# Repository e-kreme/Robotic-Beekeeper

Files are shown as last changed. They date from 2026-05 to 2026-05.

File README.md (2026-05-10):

# Robotic Beekeeper
Bachelor's thesis at Brno University of Technology, Faculty of Information Technology (VUT FIT), 2025/2026.

**Author:** Eliška Křeménková (xkremee00)\
**Supervisor:** doc. RNDr. Pavel Smrž, Ph.D.

## Overview

An automated beehive monitoring system consisting of two hardware nodes and a server:

- **Sensor node (ESP32-S3)** - measures hive weight, outdoor temperature, and indoor temperature, humidity, and pressure, publishes readings to an MQTT broker every 5 minutes
- **Camera node (Raspberry Pi 5)** - detects and counts bees at the hive entrance using a YOLO11n model with ByteTrack tracking, distinguishes bees carrying pollen and direction of movement
- **Server (Raspberry Pi 4)** - receives all data via MQTT, stores it in a SQLite database, runs anomaly detection using LightGBM predictions, and visualises everything in Grafana with email alerts

## Repository Structure

```
.
├── data/
│   ├── BeeObserver/          # BeeObserver (BoB) dataset used for model training
│   │   └── {year}/49.csv
│   ├── sensor_data.csv       # Real sensor readings from the deployment period
│   └── bee_count_log.csv     # Real bee traffic counts from the deployment period
│
├── docs/
│   ├── installation_guide.md # Step-by-step setup for all nodes and the server
│   ├── user_manual.md        # How to use and monitor the system
│   └── schematic.png         # Sensor node wiring schematic
│
├── src/
│   ├── firmware/
│   │   ├── beehive.ino       # ESP32-S3 Arduino sketch
│   │   └── config.h.example  # WiFi and MQTT credentials template
│   │
│   ├── scripts/
│   │   ├── bee_counter.py                  # Camera node - real-time bee counting
│   │   ├── subscriber.py                   # Server - MQTT subscriber and database writer
│   │   ├── forecast_anomaly_detection.py   # Server - hourly prediction and anomaly detection
│   │   ├── photo_script.py                 # Utility - time-lapse photo capture (dataset collection)
│   │   └── config.py.example               # MQTT configuration template
│   │
│   ├── models/
│   │   ├── machine_learning.ipynb                      # Model training notebook (LightGBM + LSTM)
│   │   ├── lgb_separate_weight-delta-noOutlier.txt     # Trained LightGBM weight model
│   │   ├── lgb_separate_t-i-3.txt                      # Trained LightGBM temperature model
│   │   ├── lgb_feature_cols.json                       # Feature column list for inference
│   │   └── mybeesyolo11.ncnn.zip                       # YOLO11n bee detection model (NCNN format)
│   │
│   ├── config/
│   │   ├── beehive.conf                    # Mosquitto broker configuration
│   │   ├── beehive-subscriber.service      # systemd service for the subscriber script
│   │   ├── contrab.example                 # Cron entry for forecast_anomaly_detection.py
│   │   ├── grafana.ini.smtp.example        # Grafana SMTP email alert configuration template
│   │   └── Beekeeper5_grafana_export.json  # Grafana dashboard export
│   │
│   └── 3d_models/                          # SolidWorks parts and assembly for the hive scale and camera module
│
├── tex_src/                  # LaTeX source files for the thesis
├── plakat.pdf                # Project poster
├── requirements.txt          # Python dependencies
├── LICENSE
└── README.md
```

## Data

### Deployment Data

Real sensor and camera data collected during the deployment period (April–May 2026):
- `data/sensor_data.csv` - weight, temperatures, humidity, pressure (5-minute intervals)
- `data/bee_count_log.csv` - individual bee crossing events with direction and class
Both files were exported from the SQLite database on the Raspberry Pi 4.

### Training Data

The LightGBM and LSTM models were trained on the **BeeObserver (BoB)** dataset - sensor data from instrumented honey bee colonies recorded in Germany between 2019 and 2022. Colony 49 is used across all four available years.

Dataset source: [BeeObserver on Zenodo](https://zenodo.org/records/10407693)

## Quick Start

See [`docs/installation_guide.md`](docs/installation_guide.md) for full step-by-step instructions for all three nodes and the server.

### Sensor Node (ESP32-S3)

1. Install Arduino IDE and required libraries (see installation guide)
2. Copy `src/firmware/config.h.example` to `src/firmware/config.h` and fill in credentials
3. Flash `src/firmware/beehive.ino`

### Camera Node (Raspberry Pi 5)

1. Create a virtual environment with system-wide packages and install dependencies
2. Copy `src/scripts/config.py.example` to `src/scripts/config.py` and fill in credentials
3. Unzip the YOLO model to `~/Desktop/beehive/`
4. Run `python3 src/scripts/bee_counter.py`

### Server (Raspberry Pi 4)

1. Install Mosquitto, SQLite, and Grafana (see installation guide)
2. Start the subscriber as a systemd service
3. Add the cron job for anomaly detection
4. Import the Grafana dashboard from `src/config/Beekeeper5_grafana_export.json`

## Model Training

The `src/models/machine_learning.ipynb` notebook contains the full training pipeline:
- Data loading and feature engineering from the BeeObserver dataset
- LightGBM training (separate models for weight delta and internal temperature)
- LSTM training as a comparison model
- Anomaly detection evaluation
Run from the repository root with the `data/BeeObserver/` directory present.

## License

See [`LICENSE`](LICENSE).

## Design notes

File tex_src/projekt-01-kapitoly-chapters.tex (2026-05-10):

\chapter{Úvod}
Včely medonosné patří mezi nejvýznamnější opylovače a jejich úloha v~zemědělství i ochraně krajiny je nezastupitelná. V~posledních desetiletích však včelstva čelí rostoucímu tlaku způsobenému parazity, onemocněními i invazivními predátory. Včasná detekce těchto hrozeb je pro včelaře klíčová, avšak tradiční vizuální kontrola úlu je časově náročná, závislá na~zkušenostech včelaře a zachycuje stav včelstva pouze v okamžiku návštěvy stanoviště.

Moderní technologie umožňují tato omezení částečně překonat prostřednictvím kontinuálního automatizovaného monitorování. Měření fyzikálních veličin, jako jsou hmotnost úlu, vnitřní teplota nebo vlhkost, umožňuje sledovat stav včelstva nepřetržitě po celý rok a odhalit odchylky signalizující problém ještě před fyzickou kontrolou. Kamerová analýza česna pak doplňuje senzorová měření o~přímé informace o~letové aktivitě včelstva.

Tato práce navazuje na bakalářskou práci Bc.~Kataríny Chovancové, která se zabývala návrhem kamerového systému pro monitorování česna úlu s~detekcí včel, matky a vosy. Cílem předkládané práce je původní řešení rozšířit tak, aby poskytovalo komplexnější vhled do stavu a zdraví včelstva.

Osobní motivací pro volbu tématu je propojení dvou oblastí zájmu -- včelařství a moderních technologií. Včelařství je v~mé rodině dlouhodobě zakořeněno, protože můj otec se mu již řadu let věnuje. Právě z pozorování jeho práce pramení snaha včelám lépe porozumět a přispět k usnadnění péče o~ně.

Práce je členěna do několika kapitol. Kapitola~\ref{vcelareni} uvádí čtenáře do problematiky včelařství, představuje základy oboru, popisuje nejvýznamnější choroby, škůdce a patologické stavy včelstev, definuje měřitelné veličiny relevantní pro monitorování a shrnuje vybraná existující komerční řešení. Běžně používaným hardwarovým komponentám v oblasti monitorování včelstev se věnuje kapitola \ref{sec:hardware}. Kapitola \ref{sec:iot_komunikace} představuje principy Internetu věcí a komunikačních technologií, které tvoří základ pro volbu komunikační infrastruktury navrženého systému. Kapitola \ref{sec:strojove_uceni} pojednává o~metodách strojového učení, predikci časových řad a detekci anomálií, jež jsou využity v~analytické vrstvě systému, a dále o~přístupech počítačového vidění, na~nichž je založeno kamerové sledování česna a klasifikace včel. Kapitola~\ref{sec:zhodnoceni_navrh} na~základě teoretického rozboru formuluje požadavky na~systém a představuje jeho návrh. Zbývající kapitoly popisují fyzickou konstrukci, implementaci a testování zařízení v~reálných podmínkách na~včelařském stanovišti, porovnávají dosažené výsledky s~existujícími řešeními a navrhují možné směry budoucího vývoje.

\chapter{Včelařství a moderní technologie} \label{vcelareni}
Tato kapitola se zabývá problematikou včelařství z~pohledu současných technologických možností a jejich využití při monitorování včelstev. Nejprve je stručně představeno včelařství jako obor. Následně je rozebrán význam sledování stavu úlu, které umožňuje včasnou detekci problémů a efektivnější řízení včelstva. Důležitá část kapitoly je věnována identifikaci měřitelných veličin, které lze využít k hodnocení stavu včelstva, například hmotnosti úlu, teploty či vlhkosti. Součástí kapitoly je také přehled nejvýznamnějších chorob, škůdců a patologických stavů, které mohou včelstva postihovat. Závěrem jsou představeny existující komerční systémy, jejich vlastnosti a omezení.

\section{Úvod do včelařství}
Včelařství neboli \textit{apikultura} je jedním z~nejstarších řemesel s~historií datující se až do~starověku \cite{Gerstmeier}. Jedná se o~oblast na pomezí biologie, zemědělství a ochrany krajiny. V~širším smyslu spočívá včelařství v~chovu a péči o~včelstva umístěná v~umělých a uspořádaných úlech. 

V~této práci je pod pojmem \textit{včela} vždy míněna včela medonosná (\textit{Apis mellifera}), druh společenského blanokřídlého hmyzu vytvářejícího trvalé kolonie (včelstva) s~kastovní organizací (matka, dělnice, trubci). Na území České republiky se standardně chová v~rámci včelařské praxe \cite{naturaBohemica}.

\section{Význam monitorování úlu}
Tradiční metodou sledování stavu úlu je vizuální kontrola, v~tomto kontextu jsou tím míněny zejména kontroly na začátku včelařské sezóny. Včelař typicky začíná pozorováním česna, kde se zaměřuje na letovou aktivitu včel, její charakter a intenzitu, množství mrtvých včel či přínos pylu. Zkušenější včelaři dokáží dle barvy pylu rozeznat jednotlivé druhy rostlin, ze~kterých pyl pochází \cite{Storch}. Již na základě těchto vjemů lze určit, v~jakém stavu se včelstvo nachází po zimním období.

Následně včelař prohlíží podložky pod úlem, kde lze nalézt další indicie k~vitalitě včel. Zde lze například sledovat spad kleštíka včelího (\textit{Varroa destructor}) způsobujícího onemocnění zvané \textit{varroáza}, poškozené včely či uhynulý plod \cite{Gerstmeier}. Teprve v~závěrečné fázi prohlídky dochází k~otevření úlu a kontrole jeho vnitřního stavu.

Tradiční inspekce představuje základní nástroj chovu včel, jelikož včelaři umožňuje v~reálném čase vyhodnocovat jejich sílu, zdravotní stav a potřebu dalších zásahů. Při jediné návštěvě tak lze získat komplexní přehled o~množství zásob, přítomnosti matky, případných příznacích onemocnění nebo nedostatku prostoru. Na základě těchto poznatků je pak včelař schopen provést odpovídající zásah, například přikrmování, rozšíření prostoru nebo léčbu. Velmi důležitou součást tvoří průběžná dokumentace zjištěného stavu, která umožňuje sledovat vývoj včelstva v~čase a účinnost jednotlivých, typicky léčebných, zásahů \cite{Gerstmeier}.

Přesto mají tyto kontroly své limity. Bývají vysoce závislé na znalostech a zkušenostech samotného včelaře, ale i fyzicky a časově náročné, zejména pro odlehlá stanoviště. Zároveň poskytují pouze okamžité informace o~stavu, nelze tedy zachycovat plynulé změny probíhající mezi jednotlivými návštěvami. Za příklad lze uvést pozvolné slábnutí včelstva v~důsledku nemocí nebo dlouhodobého nedostatku snůšky \cite{Cecchi}. Časté a neopatrné otevírání úlu může narušit vnitřní mikroklima, zvyšovat stres včel i poškozovat plod vlivem nepříznivých venkovních podmínek. Některé patologické stavy jsou v~raných fázích obtížně rozpoznatelné pouhým okem a vyžadují laboratorní vyšetření nebo specializované diagnostické metody -- tradiční vizuální prohlídka je sama o~sobě nemusí včas zachytit \cite{Ritter}.

V~následující části textu budou představeny nejvýznamnější choroby, škůdci a patologické stavy, které mohou včelstva postihovat. Vybraný přehled se zaměřuje zejména na~onemocnění plodu a dospělých včel, na~parazity a další infekce.

\subsubsection*{Varroa destructor}
\textit{Varroa destructor}, česky kleštík zhoubný či kleštík včelí, je parazitický roztoč, který způsobuje onemocnění zvané varroáza. Původem pochází z~oblasti Indie a jihovýchodní Asie, v~současné době je však rozšířen prakticky po celém světě. Výjimku tvoří Austrálie a Oceánie. V~Československu se poprvé objevil v~roce 1978 \cite{varroaza}.

V~současnosti se jedná o~jedno z~nejzávažnějších onemocnění včelstev. Roztoč parazituje jak na dospělých včelách, tak na plodu. Živí se hemolymfou, tedy tělní tekutinou larev a kukel, u~dospělých včel pak převážně tukovým tělískem, navíc tím může přenášet i další nakažlivé nemoci. Samička roztoče do plodové buňky vniká těsně před jejím zavíčkováním. V~buňce proběhne kompletní vývoj parazita a po vylíhnutí včely spolu s~ní vyběhne 2--6 oplozených samic roztoče, přičemž každá z~nich může tento proces zopakovat až sedmkrát \cite{vuvVarroaza}. Parazit častěji napadá trubčí plod, jelikož trubci jej dokážou přenést i do okolních kolonií, matečníky nenapadá.

Napadení způsobuje poškození stavby těla vylíhnutých včel, jako například deformovaná křídla, zkrácený zadeček. Pokud lze spatřit kleštíka na dospělém jedinci, bývá včelstvo zpravidla již velmi silně napadeno. I~když včelstvo navenek nevykazuje zřejmé příznaky, nemoc jej oslabuje, což může spolu s~dalšími vlivy (virózy, nedostatek potravy) vést k~úhynu celé kolonie \cite{Ritter}.

Kvůli závažnosti tohoto onemocnění musí každý registrovaný včelař povinně výskyt roztoče sledovat a včelstva léčit. Výsledky se poté evidují. Povinná je také kontrola zimní měli na přítomnost parazitů a případné navazující léčebné opatření.

\begin{figure}[H]
	\centering
    \begin{subfigure}[b]{0.5\textwidth}
        \centering
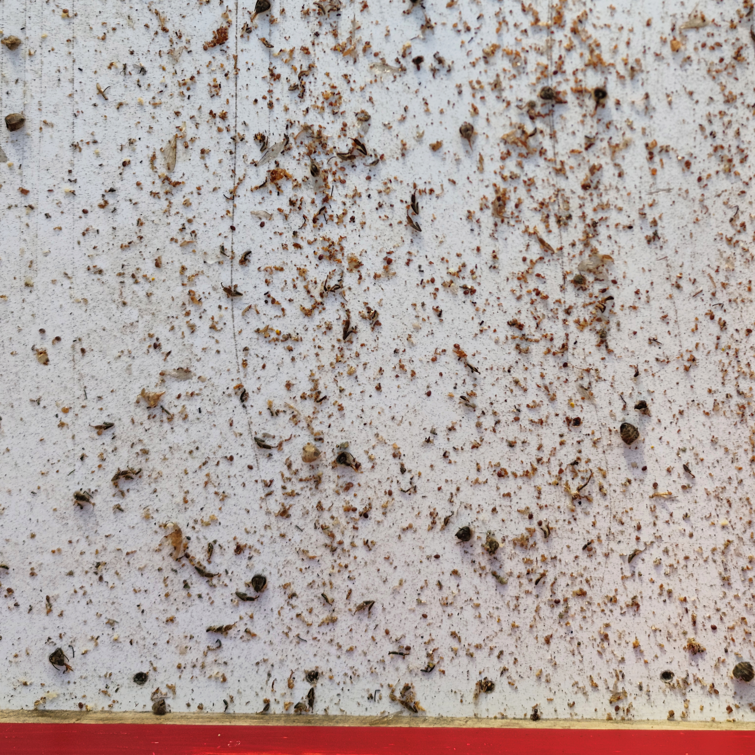
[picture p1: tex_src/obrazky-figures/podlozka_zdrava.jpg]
        
        \caption{Zdravé včelstvo}
        \label{fig:podlozka_zdrava}
    \end{subfigure}\hfill\begin{subfigure}[b]{0.5\textwidth}
        \centering
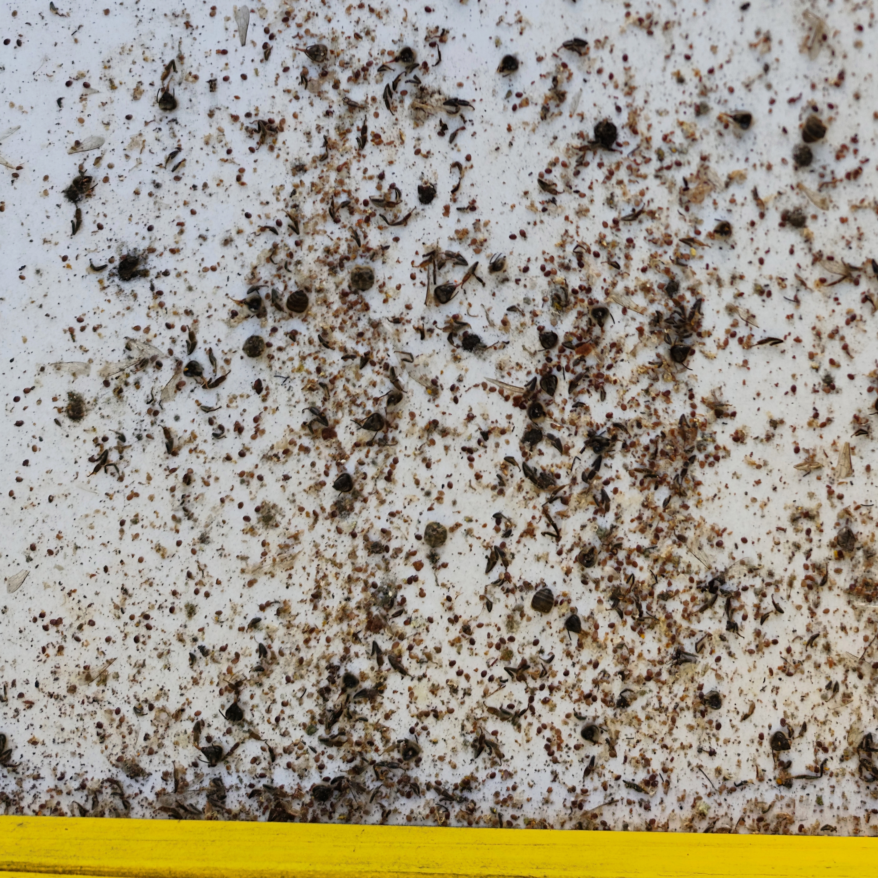
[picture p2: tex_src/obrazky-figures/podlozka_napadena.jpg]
        
        \caption{Napadené včelstvo}
        \label{fig:podlozka_napadena}
    \end{subfigure}
	
	\caption{Srovnání podložky zdravého a napadeného včelstva při podzimním léčení. Vlevo podložka s~minimálním spadem roztoče \textit{Varroa destructor}, vpravo s~výrazným výskytem.}
	\label{fig:srovnani_spadu}
\end{figure}

\subsubsection*{Další onemocnění}
Mezi další nemoci lze zařadit mor včelího plodu. Jedná se o~vysoce nakažlivé bakteriální onemocnění zavíčkovaného plodu, jehož původcem je bakterie \textit{Paenibacillus larvae}. Dospělé jedince nenapadá, ti však mohou nemoc přenášet, například při loupežích v~jiných úlech. Nemoc může mezi jednotlivými koloniemi přenést i včelař, a to křížovou kontaminací při kontrolách.

Spóry této bakterie dokážou přežít v~prostředí úlu (plásty, med, úlové vybavení) až desítky let. K~nákaze dochází po pozření těchto spor larvami, jež následně umírají. Nákazu lze poznat propadlými a děravými víčky, hnilobou, zbytky plodů a zejména pak zápachem. Při silném rozvoji onemocnění postihuje většinu plodu, v~důsledku čehož včelstvo slábne a může až uhynout \cite{Ritter}.

Mor včelího plodu je považován za neléčitelné onemocnění, proto má mnoho zemí velmi striktní hygienická a likvidační opatření. Při nálezu výskytu ho musí včelař dle zákona neprodleně oznámit, z~postižené kolonie je odebrán vzorek a zaslán do laboratoře. Napadenou kolonii pak musí majitel zlikvidovat, typicky utracením včelstva a spálením veškerého kontaminovaného materiálu či dekontaminací ozářením \cite{csvMor}.

Existuje také evropský mor včelího plodu, který naopak napadá otevřený, nezavíčkovaný plod, jenž hyne ještě před zavíčkováním. Toto onemocnění ale nebývá vždy fatální pro celé včelstvo \cite{Ritter}.

\subsubsection*{Škůdci}
Nemoci a parazité nejsou tím jediným, co včelstva zatěžuje. Významnou roli v~této oblasti hrají různí škůdci, kteří samotné včely loví, rabují zásoby a zabíjejí larvy. I samotné včely často rabují okolní kolonie.

Vosy a sršně patří mezi nejvýznamnější přirozené predátory včel, protože napadají jak včely, tak i oslabená či špatně chráněná včelstva. Na včely si počkají před česnem, kde je loví a odnášejí jako potravu pro své vlastní larvy. Případně pronikají až dovnitř úlu, kde rabují med, pyl i plod. V~evropských podmínkách mezi hlavní druhy těchto škůdců patří vosa obecná (\textit{Vespula vulgaris}) a sršeň obecná (\textit{Vespa crabro}). 

Zdravé včelstvo si s~několika jedinci dokáže poradit samo. Proti sršním se například využívá zúžení vstupu do úlu kvůli jejich velikosti. Problém však v~poslední době tvoří jiný druh sršně, proti kterému se stala tato metoda ochrany neúčinná. Tím je sršeň asijská (\textit{Vespa velutina}), jedná se o~invazivní druh, který se rozšiřuje po Evropě. V~České republice se výskyt potvrdil na podzim roku 2023 \cite{svscrSrsenAsijska}. Je o~něco menší než sršeň obecná a redukce česna ji proto nedokáže zastavit. Evropské včely se proti ní samy bránit příliš nedokážou, proto mohou být útoky těchto predátorů pro včelstvo i fatální \cite{monceau2014}. Článek navíc uvádí, že ve Francii, kam byla sršeň do Evropy v~roce 2004 zavlečena, bylo v~roce 2010 oslabeno či zničeno 30\,\% úlů.

Z~řad drobnějších škůdců lze uvést například zavíječe voskového. Larvy tohoto motýla se živí voskem, zejména plásty, ve kterých se nachází včelí plod. Dále pak i mravenci, kteří si vytvářejí hnízda v~polystyrenové vrstvě zateplených úlů \cite{Ritter}.

V~neposlední řadě se jedná o živočichy, jako jsou ptáci nebo drobní hlodavci, kteří úl poškozují spíše mechanicky. V~zimě jej mohou vyhledávat jako úkryt a zdroj potravy.

\subsubsection*{Rojení}
Rojení představuje přirozený způsob rozmnožování včelstev, kdy se jedno silné včelstvo rozdělí na dvě nebo více částí. Typicky stará matka vytváří roj a úl opouští, aby ustoupila matce nové. Pro včelaře je velmi obtížné se na tuto událost připravit. Většinou se jí snaží předcházet s~využitím různých opatření, například rozšířením úlu, tedy přidáním takzvaných \textit{rámků s~mezistěnkou}, aby měly včely další prostor pro ukládání zásob. K~dalším opatřením se řadí přistřižení matčiných křídel \cite{ivcelarstviRojeni}. Nejdůležitější jsou však pravidelné prohlídky rámků, při nichž včelař kontroluje, zda včely nezakládají \textit{matečníky}, tedy buňky, ze kterých vyrostou včelí matky.

Rojení probíhá od jara až do konce června a lze jej rozdělit na \textit{prvoroj}, kdy vylétá stará matka, \textit{druhoroj}, kdy vylétá nová neoplozená matka. Někdy může dojít ještě k~dalším rojením: \textit{třetiroj} atd. Takové chování včel se nazývá \textit{rojová nálada}. K~jejím znakům se řadí velké množství včel, plodu, zásob a snůšky, také zakládání matečníků. Tyto buňky lze nalézt na spodní straně plástu a jsou výrazně větší než ostatní. Čas rojení nastává v~devátý den od zavíčkování matečníku \cite{Gerstmeier}.

I~přesto, že se jedná o~naprosto přirozený proces v~životě včelstva, je pro včelaře negativní, jelikož tím přichází o~velkou část zásob i létavek. Včelstvo pak zůstává oslabené a nová matka neklade vajíčka, protože ještě není oplodněná. Včelař má proto za cíl vyletělý roj chytit a buď z~něj vytvořit novou kolonii, nebo včely vrátit zpět k~té původní.

\section{Měřitelné veličiny} \label{sec:veliciny}
Moderní přístupy k~monitorování včelstev se opírají o~kontinuální měření fyzikálních veličin přímo v~úlu či jeho bezprostřední blízkosti. Přitom žádná veličina není sama o~sobě dostačující pro poskytnutí uceleného obrazu o~stavu dané kolonie -- teprve jejich kombinace a sledování v~čase umožňuje rozpoznat jak normální průběh včelařského roku, tak odchylky značící problém \cite{Cecchi}.

V~rámci systémů využívajících senzory pro monitoring se nejčastěji měří hmotnost, teplota a relativní vlhkost. Některá zařízení přidávají ještě měření atmosférického tlaku, zvuku, oxidu uhličitého či aktivity na česně \cite{Sabic2025}. V~následující části textu jsou popsány základní veličiny -- jejich způsob měření, typické hodnoty v~průběhu roku a znaky rizikových stavů.

\subsubsection*{Hmotnost}
Hmotnost celého úlu je jednou z~veličin s~nejvyšší informační hodnotou, kterou lze při monitorování včelstev sledovat. Měří se pomocí takzvaných \textit{úlových vah}, tedy tenzometrickým snímačem umístěným pod úlem. Získaná data se pak často přenášejí do vzdáleného úložiště. Výhodou tohoto způsobu měření je, že nevyžaduje žádný zásah do úlu a může probíhat nepřetržitě po celý rok.

Hmotnost se v~průběhu roku mění v~závislosti na sezóně. Na jaře a v~létě, v~době snůšky, dochází k~pravidelnému přírůstku -- včely nosí pyl a nektar, matka klade vajíčka a zásoby přibývají. Zároveň dochází i k~denním změnám: v~ranních hodinách hmotnost poklesne, když včely opouštějí úl. Ve večerních hodinách naopak stoupá, jak se včely vracejí s~nektarem \cite{Cecchi}. V~zimním období naopak hmotnost pozvolna klesá, protože včelstvo spotřebovává zásoby. Průměrná zimní spotřeba se pohybuje okolo 6--15 kg, v~závislosti na velikosti kolonie a délce zimního období \cite{domaciVcelarstvi}. 

\begin{figure}[H]
	\centering
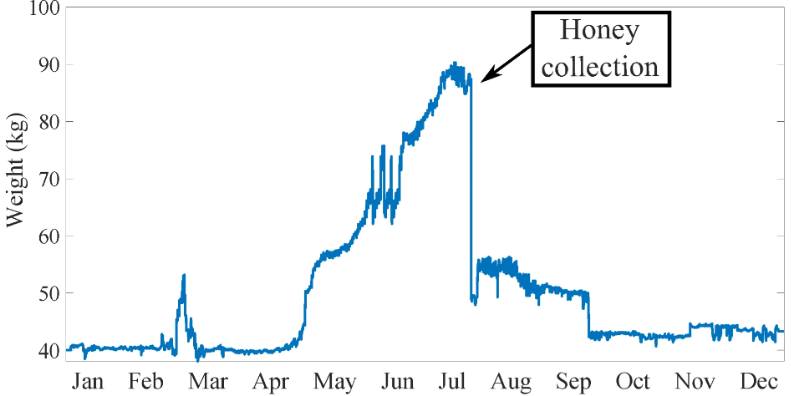
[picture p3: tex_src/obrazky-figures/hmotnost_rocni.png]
    
	\caption[Roční průběh hmotnosti úlu.]{Roční průběh hmotnosti úlu.\footnotemark}
	\label{fig:hmotnost_rocni}
\end{figure}
\footnotetext{Graf pochází z~\cite{Cecchi}, Obrázek 3d.}

Právě v~interpretaci odchylek od těchto očekávaných vzorců spočívá největší přínos průběžného vážení. Náhlý pokles hmotnosti v~řádu 3--4 kg, který lze vidět na obrázku \ref{fig:hmotnost_rojeni}, bývá charakteristickým příznakem rojení. Velká část \textit{létavek} i stará matka úl opouštějí, čímž se jeho hmotnost jednorázově výrazně sníží \cite{Cecchi}. Tento projev je na hmotnostní křivce dobře identifikovatelný a může sloužit jako základ pro včasné upozornění včelaře, který tak může roj odchytit nebo alespoň reagovat na pozměněný stav včelstva.

\begin{figure}[H]
	\centering
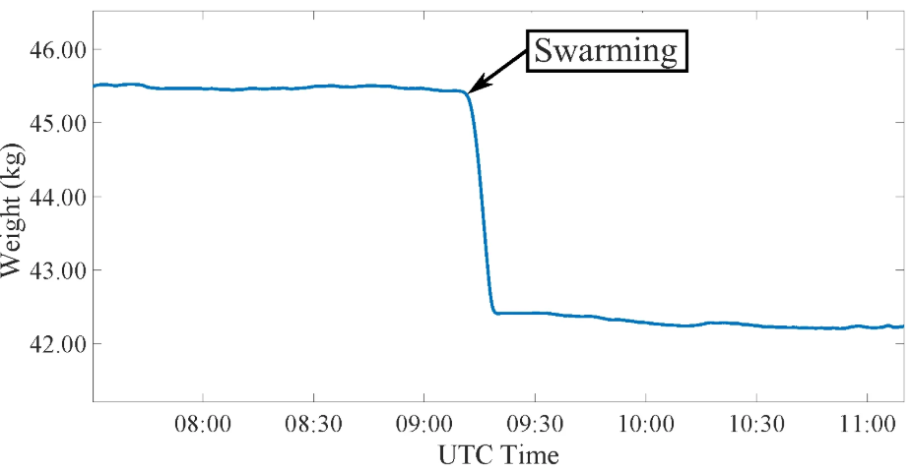
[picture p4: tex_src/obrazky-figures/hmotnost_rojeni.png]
    
	\caption[Změna hmotnosti při události rojení.]{Změna hmotnosti při události rojení.\footnotemark}
	\label{fig:hmotnost_rojeni}
\end{figure}
\footnotetext{Graf pochází z~\cite{Cecchi}, Obrázek 12a.}

Dále pak postupný úbytek hmotnosti mimo zimní období může znamenat hladovění kolonie, kdy včelám nestačí vlastní zásoby a je potřeba přikrmování. Naopak náhlý a extrémní pokles hmotnosti téměř na nulu může indikovat krádež nebo převrácení úlu \cite{dsouza2023hivelinkiotbasedsmart}.

Při sledování těchto změn hmotnosti v~čase je však vždy důležitý sezónní kontext, jelikož stejná změna může mít zcela jiný význam například v~lednu a v~červenci. Z~hlediska datové kvality se ukazuje jako vhodné pracovat s~průměry za delší časové intervaly nebo provádět měření ve stejnou denní dobu, protože surová data mohou obsahovat výrazný šum způsobený pohybem včel, větrem nebo vibracemi \cite{Cecchi}.

\subsubsection*{Teplota}
Teplota je veličinou, která odráží biologickou aktivitu včelstva nejpříměji, míněna je samozřejmě teplota uvnitř úlu. Okolní teplota slouží spíše jako kontext k~hodnotám hmotnosti či letové aktivity (nízká teplota znamená nízkou aktivitu včel). Včely disponují schopností aktivně regulovat teplotu uvnitř úlu v~závislosti na aktuálních potřebách včelstva \cite{Tautz2021}. Měření teploty proto poskytuje přímý vhled do fyziologického stavu kolonie.

Pro měření se nejčastěji využívá digitálních teplotních senzorů, případně kombinovaných, které kromě teploty měří i další veličiny, jako relativní vlhkost či atmosférický tlak. Zásadní roli hraje i umístění senzoru: nejpřesnější informace o~stavu plodového hnízda poskytuje senzor umístěný přímo uprostřed meziplástového prostoru v~centru úlu. Gradient teploty uvnitř úlu je přitom velmi výrazný -- od středu k~okrajům může dosahovat i 10--15\,°C \cite{Stabentheiner2021}, proto systémy s~více senzory poskytují lepší obraz o~stavu kolonie.

V~době, kdy matka klade vajíčka a v~úlu se nachází plod, udržují včely v~plodovém hnízdě teplotu v~úzkém rozmezí 34--36\,°C \cite{Stabentheiner2021} (kniha \textit{Fenomenální včely} \cite{Tautz2021} uvádí interval 33--36\,°C). Tato hodnota podmiňuje správný vývoj larev a kukel. Odchylky od zmíněné teploty mohou mít negativní dopad na kvalitu vylíhnutého plodu. Existence stabilní teploty v~tomto rozmezí je proto spolehlivým nepřímým ukazatelem přítomnosti matky a aktivity plodového hnízda. Naopak pokles teploty v~centru úlu pod 30\,°C v~průběhu hlavní sezóny by měl být signálem k~fyzické kontrole, jelikož může naznačovat ztrátu včelí matky nebo jiný závažný stav kolonie.

V~zimním období včely netvoří aktivní plodové hnízdo a shlukují se do tzv. \textit{zimního chomáče}. Ten funguje jako živý izolátor: teplota v~jeho středu se pohybuje okolo 15--25\,°C \cite{Gerstmeier}, zatímco na povrchu může klesnout k~10\,°C. To je totiž teplota, při níž včely ztrácejí schopnost pohybu \cite{Tautz2021}. Postupný nárůst teploty od přelomu ledna a února signalizuje, že matka opět začíná klást vajíčka a včelstvo se připravuje na jaro.

Teplotní data jsou také jedním z~nejspolehlivějších indikátorů blížícího se úhynu kolonie. Studie Minaud et al. \cite{Minaud} ukázala, že sledování teplotní variability uvnitř úlu v~průběhu zimování umožňuje s~přesností přes 96,8\,\% rozlišit přezimující kolonie od těch, které zimu nepřežijí. Umírající včelstvo postupně ztrácí schopnost udržovat potřebnou teplotu, včely ztrácejí schopnost pohybu a vnitřní teplota se přibližuje teplotě venkovní, viz obrázek \ref{fig:teplota_zima_uhyn}.

\begin{figure}[H]
	\centering
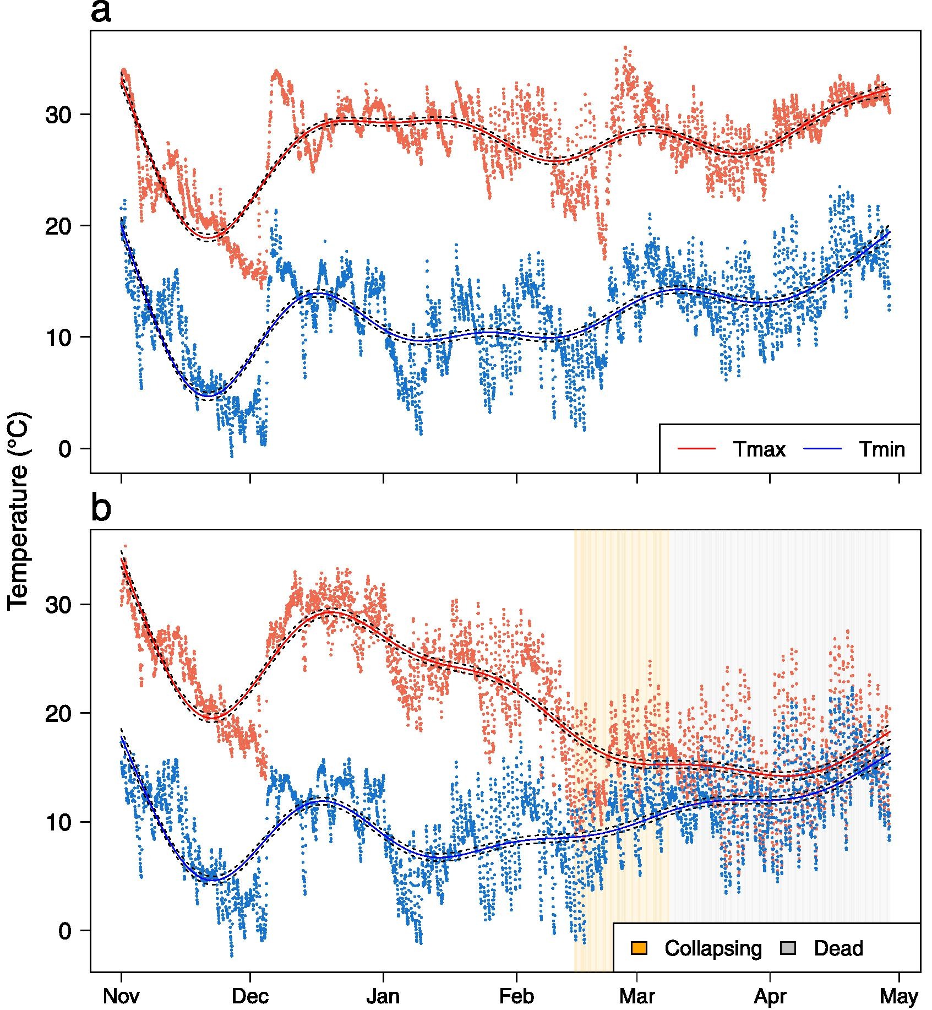
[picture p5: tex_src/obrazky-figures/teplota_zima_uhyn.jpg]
    
	\caption[Porovnání zdravého (a) a uhynulého (b) včelstva v~zimním období.]{Porovnání zdravého (a) a uhynulého (b) včelstva v~zimním období.\footnotemark}
	\label{fig:teplota_zima_uhyn}
\end{figure}
\footnotetext{Grafy pochází z~\cite{Minaud}, Obrázek 2.}

Naopak krátkodobý nárůst teploty v~kombinaci s~nárůstem vlhkosti může předcházet samotnému odletu roje. Roj se zahřívá, a až jeho teplota stoupne na 35\,°C, vyletí ven \cite{Tautz2024}. Včely před rojením větrají úl (víření křídel na česně) a zvyšují svou pohybovou aktivitu, což se projeví i na senzorech \cite{Cecchi}.

V~letních měsících může naopak přílišné horko způsobit, že včely začnou intenzivně větrat česno. Pokud tyto snahy nestačí, včely se na česně začnou ve větším množství shromažďovat. V~extrémních případech je nutný zásah včelaře \cite{Stabentheiner2021}.

\subsubsection*{Relativní vlhkost} \label{veliciny-vlhkost}
Ačkoliv se může na první pohled zdát, že se jedná o~veličinu, která není tolik důležitá, relativní vlhkost úzce souvisí s~několika klíčovými procesy v~životě kolonie. Měří se pomocí kapacitních senzorů. Praktickým problémem při dlouhodobém nasazení jsou samotné včely, které mohou vnitřní senzory obalovat propolisem či voskem. To může způsobovat odchylky měření až úplný výpadek senzoru, což lze následně pozorovat například na grafu naměřených hodnot. Tento jev byl zdokumentován při měření plynů v~úlu \cite{Rigakis2023} a autoři problém vyřešili uložením senzoru do ochranné krabičky.

Nejzásadnější funkcí regulace vlhkosti v~úlu je zpracování nektaru na med. Čerstvě přinesený nektar obsahuje 60--80\,\% vody. Aby byl med kvalitní a nezačal kvasit, musí včely jeho vlhkost snížit pod 20\,\% \cite{nettie}. Tohoto dosahují aktivním větráním. Díky tomuto procesu vlhkost v~úlu výrazně stoupá, zejména v~nočních hodinách, kdy odpařená voda zůstává uvnitř. Sledování nočního nárůstu vlhkosti může sloužit jako nepřímý indikátor intenzity snůšky.

Pro správný vývoj a přežití vajíček je nezbytná relativní vlhkost alespoň 55\,\% v~oblasti plodového hnízda, ideální je však až 90--95\,\% \cite{Linton2019}. Samotné plodové hnízdo udržují včely v~rozmezí přibližně 40--70\,\% RH prostřednictvím aktivního větrání \cite{Linton2019}. Dlouhodobá vlhkost výrazně přesahující tuto hranici, nebo naopak klesající pod 40\,\% může signalizovat poruchu regulačního mechanismu, tedy oslabení nebo zmenšení kolonie.

V~zimním období představuje nadměrná vlhkost jedno z~rizik, která mohou přezimující včelstvo oslabit nebo poškodit. Kondenzace vlhkosti na stěnách úlu a plástech může vést ke tvorbě plísní, poškození zimních zásob nebo přímo k~navlhnutí chomáče, což výrazně zvyšuje energetické nároky na jeho vytápění \cite{Linton2019}. Správné větrání úlu v~zimě proto není jen otázkou eliminace vlhkosti z~dechu včel, ale přímo podmínkou úspěšného přezimování.

Relativní vlhkost může být také jedním z~indikátorů předcházejícího rojení. Bezprostředně před odletem roje bylo v~některých měřeních zaznamenáno krátkodobé zvýšení jak teploty, tak vlhkosti uvnitř úlu \cite{Cecchi} -- pravděpodobně v~důsledku zvýšené aktivity a tělesného tepla shlukujících se rojových včel. Samotná vlhkost však nestačí jako jediný prediktor, proto je vhodné ji kombinovat s~teplotou či dalšími veličinami.

\subsubsection*{Letová aktivita}
Letová aktivita představuje počet včel procházejících česnem za jednotku času a jejich směr pohybu. Jedná se o~veličinu odrážející vnější sběrací část včelstva. Zatímco teplota a hmotnost informují převážně o~dění uvnitř úlu, letová aktivita zachycuje, jak intenzivně kolonie komunikuje s~okolním prostředím \cite{Meikle2015}. Z~biologického pohledu zodpovídají za letovou aktivitu včely \textit{létavky}. Právě letová aktivita proto úzce souvisí s~dostupností snůšky v~okolí a s~celkovou silou a zdravotním stavem kolonie.

Principů pro automatizované měření této veličiny existuje celá řada. Mezi historicky nejpoužívanější patří infračervené senzory nebo fotoelektrické závory. Modernější přístupy zahrnují kapacitní senzory, RFID čipy přilepené na hrudní část jedinců, které umožňují sledování konkrétních včel, kamerové systémy zpracovávající video pomocí algoritmů pro sledování objektů nebo Dopplerův radar. Podrobnější informace uvádí sekce \ref{senzor-let}. Každá z~metod má své výhody i nevýhody týkající se přesnosti, invazivnosti, náročnosti zpracování či citlivosti na změny osvětlení nebo počasí \cite{Williams2023}.

Letová aktivita silně závisí na vnějších podmínkách, zejména na teplotě a intenzitě slunečního záření. Včely typicky nelétají při teplotách pod 10\,°C, při dešti nebo silném větru. Studie Clarke et al. \cite{Clarke2018} ukázala, že teplotou a slunečním zářením lze vysvětlit až 78\,\% variability v~letové aktivitě měřené na česnu. Tato silná závislost na počasí je na jedné straně praktickým omezením, protože naměřené hodnoty musíme interpretovat v~kontextu aktuálních meteorologických podmínek, na druhé straně právě odchylky od předpovídané aktivity mohou být chápány jako rizikový stav \cite{Meikle2015}.

Takové stavy jsou například snížená aktivita při jinak příznivém počasí, což může naznačovat oslabení kolonie, ztrátu létavek v~důsledku otravy pesticidy nebo přítomnosti predátora.

Jarní nárůst letové aktivity bývá také jedním z~nejdříve pozorovatelných signálů jarního rozvoje včelstva, a to ještě předtím, než jsou patrné změny na vahách. První orientační prolety, v~závislosti na geografické poloze, u~nás začínají přibližně od konce února, jakmile teplota překročí 10\,°C \cite{beeinfo}. V~rámci proletů se včely orientují a nosí první potravu. U~kamerových systémů lze dokonce určit dostupnost specifických druhů rostlin v~okolí úlů dle pylových roušek na zadních nožkách včel \cite{Cecchi}.

Největším praktickým omezením automatického sledování letové aktivity zůstává technická náročnost instalace a údržby senzorů. Zařízení mohou včely stresovat a ty je následně znečišťují, jak bylo zmíněno výše. Kamerové systémy jsou citlivé na venkovní světelné podmínky a vyžadují výpočetní kapacitu pro zpracování videa v~reálném čase nebo jeho archivaci. Proto se v~praxi letová aktivita měří spíše pro výzkumné účely, nikoli jako součást komerčních monitorovacích systémů pro běžné včelaře.

\section{Některá existující komerční řešení a jejich srovnání} \label{sec:komercni_reseni}
Současný trh s~technologiemi pro monitorování včelstev lze rozdělit do dvou základních kategorií. První tvoří modulární senzorová řešení, která se přidávají k~existujícímu úlovému vybavení -- typicky se jedná o~úlové váhy doplněné teplotními a vlhkostními senzory s~bezdrátovým přenosem dat. Druhou kategorii představují integrované inteligentní systémy, kde je monitorovací technologie nedílnou součástí samotného úlu, v~některých případech se jedná i o~prvky robotické automatizace. Zatímco první kategorie je zaměřena na standardního včelaře hledajícího dostupné rozšíření stávající praxe, druhá cílí na profesionální a komerční provozovatele. V~následující části textu je představeno několik komerčních řešení dostupných na trhu.

\subsubsection*{BeeSage}
Lotyšský produkt BeeSage HiveScale v2 je primárně hmotnostní systém s~důrazem na jednoduchost nasazení a mezinárodní dostupnost. Váha měří hmotnost úlu a okolní teplotu s~hodinovým intervalem, součástí zařízení je i GPS modul pro sledování polohy úlu, který slouží jako ochrana před krádeží. Zařízení komunikuje prostřednictvím SIM karty zahrnuté v~ceně (399 EUR) a data jsou dostupná přes webovou aplikaci s~možností exportu. Výrobce také pracuje na integraci akustického monitorování v~budoucích verzích produktu \cite{beesage}. 

\subsubsection*{VeluBee}
VeluBee je český produkt s~více než desetiletou historií vývoje. Aktuálně je ve~třetí generaci hardwaru a nabízí tři produktové varianty. VeluBee Hive je kompletní sada obsahující řídicí jednotku, jednu váhu a solární panel, cena začíná na 9900 Kč a zahrnuje roční licenci. VeluBee One je přídavná váha pro rozšíření stávající sestavy (od~7300 Kč). VeluBee LUNIT je specifická offline varianta s~displejem pro lokality bez internetového připojení (od~8200 Kč). Oproti jiným řešením nabízí výrazně širší softwarové funkce: webová a mobilní aplikace zahrnuje interaktivní grafy s~možností porovnání více úlů, automatickou detekci snůšky, detekci krádeže a vyrojení, včelařský deník s~fotogalerií, správu kolonií a exporty dat ve~formátu CSV. Systém podporuje připojení přes Wi-Fi i IoT sítě a nabízí možnost vzdáleného tárování (vynulování) váhy přes internet \cite{velubee}.

\subsubsection*{BeeHive Monitoring}
Slovenský e-shop BeeHiveMonitoring.com nabízí rozsáhlé produktové portfolio zahrnující jak standardní úlové váhy s~řídicí jednotkou pro jejich správu, tak specializované senzorové moduly. Takovým modulem je například produkt Hive Heart, který se vkládá přímo na~rámky v~úlu a zaznamenává teplotu, vlhkost a zvuky včelstva -- právě analýza akustického signálu umožňuje systému předpovídat blížící se rojení. Dalším zajímavým produktem je počítadlo včel u~česna s~mechanicky upraveným vstupem, který zajišťuje průchod pouze jediné včely v~daný okamžik, což umožňuje přesnější počítání, výrobce ale neuvádí, na~jakém principu počítání funguje \cite{beehivemonitoring}.

\subsubsection*{Beewise}
Izraelská společnost Beewise představuje systém zásadně odlišný od všech předchozích -- BeeHome™ není doplňkem k~existujícímu úlu, ale zcela autonomním inteligentním zařízením pro současný chov dvou až deseti včelstev. Systém je vymyšlen tak, aby dokázal pracovat zcela samostatně bez jakéhokoliv lidského zásahu. Je vybaven robotickou paží umožňující vzdálenou manipulaci s~rámky, systémem pro automatické doplňování krmiva, léčení varroázy prostřednictvím termické komory (bez použití chemikálií) a ochranou před pesticidy prostřednictvím dálkově ovladatelného uzávěru česna. Počítačové vidění poháněné umělou inteligencí nepřetržitě analyzuje snímky rámků až na~úroveň jednotlivých buněk a monitoruje počty včel. Výrobce uvádí, že systém dosahuje o~70\,\% nižší míry úhynu kolonií oproti konvenčnímu chovu \cite{beewise}.

\subsubsection*{Apisense}
Polský systém Apisense představuje unikátní přístup orientovaný primárně na~chemické složení vzduchu uvnitř úlu. Zařízení je umístěno přímo na~rámek a kontinuálně analyzuje koncentrace organických sloučenin, oxidu uhličitého a oxidů dusíku, které fungují jako indikátory zdravotního stavu kolonie -- výrobce deklaruje 95\,\% úspěšnost ve~včasné detekci onemocnění. Senzor je doplněn o~měření teploty, vlhkosti a zvuku. Ve spolupráci s~Evropskou kosmickou agenturou (ESA) je plánována i satelitní analýza okolí stanoviště pro identifikaci zdrojů nektaru a potenciálních rizik (například zemědělské plochy ošetřované pesticidy). Data jsou přenášena prostřednictvím LTE brány. Výrobce nabízí výzkumný program, v~jehož rámci jsou zájemcům zasílána zařízení zdarma výměnou za závazek spolupráce a pravidelného odesílání dat \cite{apisense}.

\subsubsection*{ApiVčelař 4.0}
Česká firma ApiCo, s.r.o., která vznikla na~základě projektu Vysokého učení technického v~Brně, nabízí ekosystém dvou vzájemně propojených IoT zařízení v~rámci platformy ApiVčelař 4.0. Prvním produktem je úlová váha ApiVáha v~nerezovém provedení zajišťující celoroční bezúdržbový provoz a je kompatibilní se všemi typy úlů. Volitelným doplňkem je ApiSenzor umísťovaný přímo na~rámek uvnitř úlu, tento senzor monitoruje vnitřní teplotu, vlhkost i frekvenci. Druhým produktem je tracker ApiStopař, rovněž umísťovaný na~rámek, který kombinuje monitoring vnitřního mikroklimatu s~GPS sledováním polohy úlu -- při detekci otřesů nebo neoprávněné manipulace zasílá okamžité upozornění e-mailem i notifikací do mobilní aplikace. Obě zařízení komunikují prostřednictvím mobilní sítě (pro úlovou váhu existuje i offline varianta) a data jsou ukládána do cloudového úložiště. Přístup do úložiště a datový paušál jsou první rok součástí ceny zařízení, v~dalších letech jsou zpoplatněny částkou 528 Kč ročně \cite{apivcelar}.

\begin{table}[H]
    \centering
    \rotatebox{90}{
        \begin{tabular}{|m{2,8cm}|m{3,1cm}|m{2,2cm}|m{2,3cm}|m{2,4cm}|m{3,8cm}|}
        \hline
            \textbf{Název zařízení} & \textbf{Měření} & \textbf{Aktualizace dat} & \textbf{Komunikace} & \textbf{Napájení} & \textbf{Cena} \\
            \hline
            BeeSage HiveScale v2 & hmotnost, vnější teplota, poloha GPS & 1 hodina & GSM & dobíjecí baterie (USB) & od 399 € (9703,48 Kč)\,\footnotemark[4] \\
            \hline
            VeluBee Hive & hmotnost, vnější a vnitřní teplota & nastavitelné & Wi-Fi, IoT síť LTE & baterie + solární panel, napájení ze sítě & od 9900 Kč  \\
            \hline
            VeluBee LUNIT & hmotnost & okamžitě (diplej) & offline & dobíjecí baterie (USB) & od 8200 Kč \\
            \hline
            Kovová úlová váha & hmotnost, venkovní teplota a vlhkost & 10 minut & Bluetooth, GSM & dobíjecí baterie & 166,25 € (4043,12 Kč)\,\footnotemark[4] \\
            \hline
            Hive Heart & vnitřní teplota a vlhkost, zvuk & 10 minut & Bluetooth, GSM & baterie & 54,04 € (1311,50 Kč)\,\footnotemark[4] \\
            \hline 
            Počítadlo včel & počet včel & 10 minut & Bluetooth, GSM & baterie & 146,58 € (3564,75 Kč)\,\footnotemark[4] \\
            \hline
            BeeHome™ & hmotnost, teplota, vlhkost, kamerový záznam rámků, pesticidy & nepřetržitě & neuvedeno & integrovaný systém se solárními panely & na vyžádání \\
            \hline
            Apisense & VOC\,\footnotemark[5], oxid uhličitý, oxidy dusíku, teplota, vlhkost, zvuk & neuvedeno & LTE & baterie & neuvedeno\\
            \hline
            ApiVáha & hmotnost, venkovní teplota & 30 minut & NB-IoT & baterie & 11690 Kč\\
            \hline
        \end{tabular}}
        \caption{Srovnání vybraných komerčních produktů pro monitorování včelstev.}
    \label{tab:porovnani_komercnich_produktu}
\end{table}

\footnotetext[4]{Měnový kurz platný ke dni 17. dubna 2026}
\footnotetext[5]{Zkratka VOC představuje označení pro těkavé organické sloučeniny}

\chapter{Hardwarové komponenty} \label{sec:hardware}
Kapitola se zaměřuje na výběr a popis hardwarových komponent, které jsou často využívány pro realizaci monitorovacího systému včelstev. Jsou zde představeny jednotlivé typy mikrokontrolérů a jednodeskových počítačů, které mohou sloužit jako řídicí jednotky systému, včetně jejich výhod a omezení z~hlediska výkonu, spotřeby a dostupnosti. Dále jsou diskutovány senzory určené pro měření fyzikálních veličin relevantních pro sledování stavu úlu, přičemž je kladen důraz na jejich přesnost, spolehlivost a vhodnost pro dlouhodobé nasazení v~terénu. V~neposlední řadě je řešena problematika napájení celého systému, zejména s~ohledem na autonomní provoz a možnost využití obnovitelných zdrojů energie, jako je solární napájení.

\section{Mikrokontroléry a jednodeskové počítače}
Výběr řídicí jednotky monitorovacího systému je jedním ze základních rozhodnutí celého návrhu. Na trhu existuje celá řada platforem lišících se výpočetním výkonem, spotřebou energie, konektivitou, cenou a ekosystémem softwarové podpory. Obecně lze tyto platformy rozdělit do dvou kategorií: \textit{mikrokontroléry} (MCU -- Microcontroller Units), tedy jednočipové systémy určené primárně pro přímé řízení hardwaru a senzorů s~nízkou spotřebou, a \textit{jednodeskové počítače} (SBC -- Single-Board Computers), které disponují plnohodnotným operačním systémem a jsou schopny zpracovávat složitější výpočetní úlohy \cite{PCBSync}. V~oblasti monitorování včelích úlů se nejčastěji setkáváme se třemi platformami: ESP32, Arduino a Raspberry Pi, přičemž každá z~nich nachází využití v~odlišné části systému nebo při odlišných požadavcích projektů.

\subsubsection*{ESP32}
ESP32 je rodina systémů na čipu (SoC) vyvinutá společností Espressif Systems, která se od~svého uvedení na trh v~roce 2016 stala jednou z~nejrozšířenějších platforem pro aplikace ~\textit{Internetu věcí} (IoT -- Internet of Things). Základ čipu tvoří dvoujádrový procesor Xtensa LX6 taktovaný na 240 MHz, integrovaná paměť SRAM o~velikosti 520 KB a paměť flash do 16 MB \cite{ESP32Datasheet}. Klíčovou vlastností, která ESP32 odlišuje od konkurenčních mikrokontrolérů, jako je Arduino, je integrovaná bezdrátová konektivita -- podpora Wi-Fi i Bluetooth bez~nutnosti externího komunikačního modulu \cite{ESP32Datasheet}.

V~kontextu monitorování úlů bývá ESP32 velmi oblíbenou volbou pro sběr dat ze senzorů a jejich odesílání do cloudu nebo na lokální server. Disponuje bohatou sadou periferií včetně rozhraní SPI, I2C, UART a PWM, které umožňují přímé připojení senzorů teploty, vlhkosti, váhových snímačů nebo kamer. Studie Hercog et al. \cite{Hercog2023} využívá právě modul na~bázi ESP32 (LilyGO TTGO T8) pro kompletní monitorovací systém úlu. Tento systém zahrnuje měření hmotnosti, teploty i vlhkosti a přenáší data přes mobilní GPRS síť na cloudovou platformu ThingSpeak. Schopnost ESP32 přecházet do režimů \textit{hlubokého spánku} (deep sleep) a probouzet se pouze v~okamžiku měření výrazně snižuje průměrnou spotřebu energie, což je klíčové pro nasazení se solárním napájením nebo baterií \cite{PCBSync}.

\subsubsection*{Arduino}
Arduino je otevřená hardwarová a softwarová platforma původně navržená pro výuku elektroniky a rychlé prototypování. Základní desky Arduino (například Uno nebo Nano) stojí na~8bitových mikrokontrolérech AVR od společnosti Microchip s~taktovací frekvencí 16 MHz a velmi omezenou pamětí -- Uno disponuje pouze 2 KB SRAM a 32 KB flash \cite{ArduinoUno}. Tato omezení sice výrazně zužují možnosti komplexního zpracování dat, na druhou stranu je Arduino díky obrovské komunitě, rozsáhlé knihovně hotových ovladačů a intuitivnímu vývojovému prostředí (Arduino IDE) ideální pro začátečníky a jednoduché senzorové aplikace.

V~oblasti monitorování úlů se Arduino uplatňuje zejména jako základní datový logger -- sbírá hodnoty ze senzorů a buď je ukládá lokálně na SD kartu, nebo předává nadřazené jednotce (například Raspberry Pi nebo ESP32). Standardní desky Arduino bez rozšiřujícího modulu bezdrátovou konektivitu nenabízejí. Je nutné přidat externí shield, což zvyšuje cenu i komplexitu zapojení \cite{ArduinoUno}. Novější modely řady Arduino MKR nebo Portenta tuto mezeru částečně vyplňují, ale za výrazně vyšší pořizovací cenu. Pro projekty vyžadující nízkou spotřebu, integrovanou konektivitu a vyšší výpočetní výkon tak ESP32 v~současné době ve~většině nových IoT nasazení nahrazuje právě Arduino \cite{PCBSync}.

\subsubsection*{Raspberry Pi}
Raspberry Pi je jednodeskový počítač (SBC) britské nadace Raspberry Pi Foundation, který na rozdíl od mikrokontrolérů jako ESP32 či Arduino spouští plnohodnotný operační systém -- standardně distribuci Linux Raspberry Pi OS (dříve Raspbian). To mu dává výrazně větší softwarovou flexibilitu: lze na něm provozovat databáze, webové servery, nástroje pro~strojové učení nebo zpracování videa, a programovat jej prakticky v~libovolném jazyce~\cite{RPiDoc}. 

\textbf{Raspberry Pi 4 Model B}, vydaný v~roce 2019, staví na čtyřjádrovém procesoru ARM Cortex-A72 taktovaném na 1,8 GHz a je dostupný ve~variantách s~1--8 GB operační pamětí LPDDR4-3200 \cite{RPi4ProductPage}. Konektivita zahrnuje Gigabit Ethernet port, Bluetooth 5.0, dva porty USB 3.0, dva porty USB 2.0, dva micro-HDMI výstupy, port CSI pro kameru a DSI pro displej. Standardní 40pinová lišta přináší zpětnou kompatibilitu s~předchozími generacemi a umožňuje připojení senzorů a rozšiřujících modulů \cite{RPi4Datasheet}.

\textbf{Raspberry Pi 5}, uvedený v~roce 2023, přináší výrazné zlepšení výkonu. Nový čtyřjádrový procesor ARM Cortex-A76 taktovaný na 2,4 GHz nabízí oproti Pi 4 znatelně vyšší výpočetní výkon. Paměť LPDDR4X-4267 běží na vyšší frekvenci, přidán byl konektor PCIe 2.0 umožňující připojení NVMe SSD (přes adaptér), a o~vstupně-výstupní operace se nově stará dedikovaný čip RP1, který výrazně zvyšuje propustnost USB a dalších periferií. Pi 5 vyžaduje napájení 5 V/5 A~(oproti 5 V/3 A~u~Pi 4) a při vyšší zátěži se doporučuje využít aktivní chlazení. GPIO lišta zůstává 40pinová a je zpětně kompatibilní s~Pi 4 \cite{Kitronik}.

\subsubsection*{Porovnání}
Volba mezi jednodeskovým počítačem a mikrokontrolérem není pouze otázkou výpočetního výkonu, ale také několika dalších aspektů. ESP32 vyniká nízkou spotřebou energie, integrovanou bezdrátovou konektivitou a přímým řízením senzorů s~bateriovým či solárním napájením. Jeho spotřeba v~aktivním režimu se pohybuje pod 1 W, zatímco Raspberry Pi při~běžném provozu typicky odebírá 3--5 W \cite{Serepas2025}. Arduino zůstává relevantní zejména pro~jednoduché senzorové aplikace nebo jako výukový nástroj, jeho omezený výkon a absence konektivity ho staví do nevýhody oproti například ESP32. Raspberry Pi naopak vyniká všude, kde je třeba spouštět složitý software, provozovat databázi nebo zpracovávat video. To je však za cenu vyšší spotřeby a nutnosti operačního systému. V~praxi se proto oba přístupy vzájemně doplňují a moderní monitorovací systémy pro včelí úly je kombinují.

\section{Senzory pro měření fyzikálních veličin}
Senzory představují základní stavební kameny každého monitorovacího systému pro včelí úl. Jejich výběr zásadně ovlivňuje přesnost naměřených dat, provozní spolehlivost, energetickou náročnost i celkovou cenu zařízení. Pro každou měřenou veličinu potom existuje celá řada typů senzorů, která se liší principem činnosti, komunikačním rozhraním, přesností a vhodností pro konkrétní nasazení. Přehled typů senzorů používaných v~existujících řešeních shrnuje článek Šabić et al. \cite{Sabic2025}, který analyzuje 135 publikací týkajících se monitorování úlů z~let 1995--2025.

\subsubsection*{Hmotnost}
Pro měření hmotnosti se v~monitorovacích systémech prakticky výhradně používají tenzometrické snímače, tzv. \textit{load cells}. Ty pracují na principu odporové tenzometrie. Kovové tělo snímače se při zatížení nepatrně deformuje, což mění odpor nalepených tenzometrů (odporových drátků) uspořádaných do Wheatstoneova můstku. Výstupní signál je velmi slabý (v~řádu mV) a vyžaduje zesílení a digitalizaci specializovaným obvodem \cite{Trent2017}.

V~praxi se nejčastěji setkáváme se dvěma konfiguracemi. \textit{Jednobodový snímač} (single-point load cell) je kompaktní prvek vhodný pro střední nosnosti a platformové váhy, kde bývá zatížení přenášeno mimo osu snímače \cite{singlePoint}. \textit{Ohybový snímač} (bending beam) nebo \textit{smykový snímač} (shear beam) patří mezi robustnější varianty používané pro vyšší nosnosti od desítek do tisíců kilogramů \cite{LoadCells}. Pro monitorování včelího úlu, jehož hmotnost se typicky pohybuje v~rozmezí 20--80 kg, jsou vhodné ohybové či smykové snímače s~nosností 50--100 kg.

Analogový výstup snímače se zpracovává 24bitovým A/D převodníkem HX711, který tvoří de facto standard v~cenově nenáročných IoT váhových aplikacích. Disponuje integrovaným nízkošumovým zesilovačem a komunikuje s~mikrokontrolérem přes jednoduché dvoudrátové rozhraní (Clock + Data) \cite{hx711}. Rozlišení 24 bitů odpovídá teoreticky více než 16 milionům diskrétních hodnot, přičemž efektivní rozlišení je v~praxi výrazně nižší kvůli mechanickým vlastnostem snímače, teplotnímu driftu a elektromagnetickému rušení. Pro~spolehlivý provoz se proto doporučuje softwarové průměrování více vzorků a pravidelná rekalibrace pomocí referenční hmotnosti \cite{Cecchi}.

Hlavní nevýhodou tenzometrických snímačů v~reálném nasazení je citlivost na vlhkost a teplotní změny. To se týká zejména levnějších snímačů bez hermetického krytí, které mohou v~průběhu měření driftovat o~jednotky až desítky gramů. Pro přesné celosezónní sledování se doporučuje volit snímače s~certifikací alespoň IP65 nebo IP67.

\subsubsection*{Teplota}
Teplotní senzory lze v~kontextu IoT monitorování včelích úlů rozdělit do několika základních kategorií: termistory, integrované digitální senzory a kombinované senzory měřící více veličin současně.

\textbf{Termistory} (zejména typ NTC -- Negative Temperature Coefficient) jsou pasivní odporové prvky, jejichž odpor exponenciálně klesá s~rostoucí teplotou. Bývají cenově dostupné, malé a mají rychlou odezvu, ale vyžadují analogový vstup mikrokontroléru, kalibraci a kompenzaci nelinearity převodní charakteristiky \cite{bhageria2026}. V~mnoha IoT aplikacích bývají nahrazovány digitálními alternativami.

\textbf{DS18B20} je digitální integrovaný obvod od firmy Maxim Integrated komunikující protokolem 1-wire. Jako jeho klíčovou vlastnost lze uvést možnost zapojení až desítek čidel na~jediný datový pin mikrokontroléru -- každé čidlo má unikátní adresu \cite{randomNerdTutorials}. Přesnost je továrně kalibrována na $\pm0{,}5$\,°C v~rozsahu $-10$ až $+85$\,°C (jinak je ale celkový teplotní rozsah $-55$ až $+125$\,°C), rozlišení lze měnit programově od 9 do 12 bitů \cite{bhageria2026}. Senzor také existuje ve vodotěsném provedení (zalitý v~nerezové sondě), díky tomu bývá často využíván i pro~měření teploty uvnitř úlu, například v~meziplástovém prostoru, kde je vystaven jak vlhkosti, tak i propolisu. Zmíněné použití lze vidět i v~článku o projektu \textit{BeeObserver} od Senger et al. \cite{BeeObserver}. Nevýhodu tvoří konverzní latence až 750 ms při nejvyšším rozlišení \cite{DS18B20datasheet}. V~praxi se mohou vyskytnout chybné hodnoty (např. $-127$\,°C) v~případě poruchy komunikace, které se musí ošetřit softwarově.

\textbf{BME280} od Bosch Sensortec je kombinovaný senzor měřící teplotu, relativní vlhkost a atmosférický tlak přes rozhraní I2C nebo SPI. Má teplotní rozsah $-40$ až $+85$\,°C s~přesností $\pm1$\,°C \cite{BME280datasheet}. Mezi nevýhody patří mírné samozahřívání čipu v~aktivním režimu, které může způsobovat naměřené hodnoty o~1--3\,°C vyšší než skutečná okolní teplota. Tuto vlastnost lze potlačit přechodem do \textit{forced mode}, kdy čip provede měření a okamžitě přejde do spánkového režimu \cite{randomNerdTutorials}. Díky trojkombinaci veličin na jednom čipu bývá BME280 oblíbenou volbou pro~meteorologické stanice a komplexní monitorovací systémy.

\subsubsection*{Relativní vlhkost}
Senzory relativní vlhkosti pracují nejčastěji na kapacitním principu, digitální pak interně převádějí tuto změnu kapacitance na teplotně kompenzovanou hodnotu relativní vlhkosti \cite{zbotic}.

\textbf{DHT22} (nebo ekvivalentní AM2302) byl po mnoho let nejrozšířenějším cenově dostupným senzorem vlhkosti a teploty v~IoT komunitě. Komunikuje 1-wire protokolem, přesnost je specifikována na $\pm2$\,\% RH a $\pm0{,}5$\,°C \cite{DHT22datasheet}. V~praxi však DHT22 vykazuje vyšší variabilitu hodnot, občasné výpadky způsobené časovací citlivostí protokolu a rychlejší degradaci při~opakované expozici vysokou vlhkostí \cite{zbotic}. 

\textbf{BME280} kombinuje měření vlhkosti ($\pm3$\,\% RH), teploty a tlaku na jediném čipu s~rozhraním I2C a SPI. Přestože jeho specifikovaná přesnost vlhkosti je formálně nižší než u DHT22, v~praktických testech poskytuje stabilnější a hladší záznamy díky rozlišení 0,008\,\%\,RH, plně digitálnímu rozhraní a tovární kalibraci všech tří veličin současně \cite{zbotic}. Projekt \textit{BeeObserver} využívá pro měření vlhkosti právě tento senzor \cite{BeeObserver}.

\textbf{SHT4x} od Sensirion představuje alternativu s~přesností $\pm1{,}5$\,\% RH v~rozsahu 0--100\,\% vlhkosti a teplotní přesností $\pm0{,}1$\,°C \cite{SHT4xdatasheet}, nabízí tak vyšší přesnost než oba výše zmíněné senzory. Disponuje zabudovaným topným elementem pro vysoušení senzoru při kondenzaci, což prodlužuje jeho životnost v~prostředí s~vysokou vlhkostí, kterým může být právě včelí úl (viz sekce \ref{veliciny-vlhkost}).

Společnou výzvu všech kapacitních vlhkostních senzorů při nasazení v~úlu tvoří postupné obalování čidel propolisem nebo voskem, což způsobuje odchylky měření nebo až úplný výpadek senzoru, jak bylo zmíněno výše (viz \ref{veliciny-vlhkost}).

\subsubsection*{Letová aktivita} \label{senzor-let}
Pro automatické sledování letové aktivity u~vchodu do úlu existuje několik principiálně odlišných přístupů, každý s~vlastními kompromisy mezi přesností, cenou a spolehlivostí. Zároveň měření této veličiny není tak běžné jako měření předchozích veličin -- objevuje se zhruba v~10\,\% případů \cite{Sabic2025}.

\textbf{Infračervené (IR) optické závory} jsou historicky nejrozšířenějším řešením. Na jedné straně tunelového průchodu česnem je umístěn IR LED vysílač, na druhé fototranzistor. Průchod včely přeruší paprsek a generuje elektrický impuls. Pro rozlišení směru pohybu jsou nutné alespoň dva páry senzorů v~sérii, směr pak udává pořadí přerušení \cite{pesovic2017}. Největší nevýhodu představuje nutnost častého odstraňování nečistot a propolisu, ale také složitější rozlišení při průchodu více včel.

\textbf{Pyroelektrické PIR senzory} detekují změny infračerveného záření v~zorném poli senzoru. Oproti optickým závorám nevyžadují tunelový průchod, stačí je nasměrovat na~prostor před česnem. Studie Aumann \& Aumann \cite{Aumann2023} prokázala, že PIR senzor disponuje dostatečnou citlivostí k~detekci i jednotlivých letících včel a umožňuje zachytit události jako je rojení, loupež nebo jiné narušení bezprostředního okolí úlu. Při výrazně nižších nákladech může poskytovat srovnatelné výsledky jako radarové, vibrační nebo video monitorovací systémy.

\textbf{Kapacitní senzory} měří změnu kapacitance způsobenou průchodem živého jedince (jehož tělo tvoří dielektrikum díky vysokému obsahu vody) mezi elektrodami. Umožňují nejen počítání průchodů, ale i odhad rychlosti a velikosti včely \cite{Campbell2005}. Výhodou je absence pohyblivých optických prvků náchylných k~znečištění, nevýhodou ale vyšší konstrukční náročnost a citlivost na vlhkost okolního prostředí.

\textbf{Kamerové systémy} s~počítačovým viděním (RGB nebo termální kamera) umožňují nejbohatší datový výstup: rozlišení směru pohybu, detekci pylu či konkrétních predátorů. Srovnávací studie \cite{Williams2022} potvrdila, že termální kamera v~kombinaci se strojovým učením dosahuje srovnatelné přesnosti s~viditelným spektrem, přičemž je méně citlivá na změny osvětlení. Nevýhodou je však vysoká cena, výpočetní náročnost zpracování videa a citlivost na povětrnostní podmínky.

\section{Napájení a využití solární energie}
Monitorovací systémy včelích úlů bývají často nasazovány v odlehlých lokalitách, kde chybí přístup k~elektrické síti. Napájení proto představuje jeden z~klíčových konstrukčních problémů, které je nutné při návrhu takového systému řešit. Je třeba zajistit nepřetržitý provoz, často po celý rok, včetně zimních měsíců, kdy bývá přísun slunečního záření minimální. Konkrétní požadavky na napájení se výrazně liší v~závislosti na použitém hardwaru monitorovacího systému. Zatímco jednoduchý senzorový uzel postavený na mikrokontroléru, využívající režimy nízké spotřeby (např. deep sleep), vystačí s~malým solárním panelem a kompaktní baterií, systémy zahrnující výkonnější jednodeskové počítače nebo kamerové moduly vyžadují podstatně robustnější zdroj energie \cite{Spaner2025}. V~praxi se nejčastěji kombinují tři prvky: solární panel jako primární zdroj energie, akumulátor jako zásobník v~období bez~slunečního záření a řídicí obvod zajišťující správné nabíjení a ochranu baterie \cite{honestbee}.

\subsubsection*{Solární panely}
Solární panely se dělí do tří základních kategorií dle použité technologie. \textit{Monokrystalické} panely (účinnost až kolem 22\,\%) jsou vyrobeny z~jediného čistého krystalu křemíku, což elektronům umožňuje snadnější pohyb. Výsledkem je nejvyšší plošná účinnost ze všech běžně dostupných typů, zároveň se ovšem jedná o~nejdražší typ panelu \cite{solarPanels}. 

\textit{Polykrystalické} panely (účinnost přibližně do 17\,\%) vznikají přetavením více křemíkových fragmentů. Výrobní proces je jednodušší a cena nižší. Při zahřátí panely vykazují o~něco nižší účinnost a mírně vyšší ztráty než monokrystalické varianty \cite{solarPanels}.

\textit{Tenkovrstvé} panely mají nejnižší účinnost, ale lépe využívají difuzní světlo při oblačnosti a vykazují menší pokles výkonu při vyšších teplotách. Nevýhodou je nutnost větší instalační plochy pro dosažení stejného výkonu \cite{solarPanels}. 

Pro venkovní IoT systémy s~omezenou plochou jsou proto ideální volbou panely monokrystalické.

\subsubsection*{Akumulátory}
Volba akumulátoru má zásadní vliv na spolehlivost a životnost napájecí soustavy, často větší než samotná volba solárního panelu. Nejrozšířenějšími technologiemi jsou \textit{bezúdržbové olověné AGM} baterie (Absorbent Glass Mat) a \textit{lithium-železo-fosfátové (LiFePO4)} baterie. 

AGM baterie jsou osvědčenou a cenově dostupnou volbou. Elektrolyt je absorbován do~skelné vaty, baterie je zcela uzavřená, nevyžaduje údržbu. Výhodou je dobrá funkčnost při~nízkých teplotách -- lze je nabíjet i pod bodem mrazu, avšak obvykle s~omezeným nabíjecím proudem \cite{winterBattery}. Díky jejich konstrukci zvládají časté nabíjení a vybíjení. Mají však nižší životnost v~řádu 200--750 nabíjecích cyklů v~závislosti na hloubce vybití. 

LiFePO4 baterie nabízejí oproti AGM řadu provozních výhod: životnost 300--6000 cyklů, nižší hmotnost při stejné kapacitě \cite{AGM-LiFePO4}. Nevýhodou je vyšší pořizovací cena a omezení nabíjení při teplotách pod 0\,°C bez speciálního systému řízení baterie (Battery Management System, BMS) s~integrovaným ohřevem \cite{winterBattery}.

\chapter{Internet věcí a komunikační technologie}\label{sec:iot_komunikace}
Tato kapitola se věnuje principům Internetu věcí (IoT) a komunikačním technologiím, které umožňují přenos dat ze sledovaného včelstva do nadřazených systémů. Nejprve je vysvětlen základní koncept IoT, včetně architektury těchto systémů a jejich typických vlastností. Následně jsou představeny vybrané komunikační protokoly a technologie vhodné pro danou aplikaci, přičemž je diskutována jejich energetická náročnost, dosah, spolehlivost a vhodnost pro použití v~podmínkách včelařství. Cílem této kapitoly je vytvořit teoretický základ pro~návrh komunikační části systému v~dalších kapitolách.

\section{Princip systémů IoT}
Termín \textit{Internet věcí} (Internet of Things, IoT) označuje síť fyzických zařízení, která jsou vybavena senzory, výpočetním výkonem a komunikačními moduly. Taková výbava jim umožňuje sbírat data z~okolního prostředí a vyměňovat si je prostřednictvím internetu či lokálních sítí bez nutnosti přímého lidského zásahu. Klíčovým přínosem IoT je schopnost kontinuálně sledovat stavy a procesy fyzického světa, automaticky reagovat na změny a zasílat získaná data ke vzdálené analýze a vizualizaci.

Architektura IoT systémů se zpravidla popisuje pomocí vícevrstvého modelu. V~základním pojetí se rozlišují tři vrstvy: \textit{percepční}, \textit{síťová} a \textit{aplikační} \cite{IoTarchitecture}. Percepční vrstva zahrnuje fyzická zařízení -- například senzory měřící teplotu, vlhkost, hmotnost nebo pohyb. Síťová vrstva zajišťuje přenos nasbíraných dat k~dalšímu zpracování prostřednictvím různých komunikačních technologií (Wi-Fi, Bluetooth, mobilní sítě apod.). Aplikační vrstva pak poskytuje rozhraní pro zpracování, ukládání a prezentaci dat typicky ve formě webových nebo mobilních dashboardů a automatizačních systémů \cite{IoTarchitecture}. Zpracování dat však nemusí vždy probíhat až v~cloudové infrastruktuře, ale i přímo u~zdroje, například s~využitím mikrokontroléru či jednodeskového počítače. Následně se pak přenášejí pouze zpracované výsledky \cite{Sabic2025}.

\section{Přehled komunikačních protokolů}
Výběr protokolu tvoří důležitou součást návrhu IoT systému. Protokol určuje, jak si spolu zařízení vyměňují zprávy, jak velká je komunikační režie, jak je zajištěno doručení zpráv a vliv komunikace na spotřebu energie. Nejrozšířenějšími protokoly v~oblasti IoT jsou MQTT, HTTP, CoAP a proprietární ESP-NOW od Espressif. Každý z~nich reflektuje odlišná návrhová rozhodnutí a hodí se pro jiné typy nasazení.

\subsubsection*{MQTT}
MQTT (Message Queuing Telemetry Transport) je odlehčený aplikační protokol postavený na modelu \textit{publish-subscribe}. Zařízení (publisher) posílá zprávy na logicky pojmenované kanály (témata, \textit{topics}) centrálnímu brokeru. Ostatní klienti (subscribers) se přihlásí k~odběru těchto témat a broker jim následně zprávy automaticky doručuje \cite{MQTTvsHTTP}. Tato vlastnost výrazně usnadňuje škálování: jeden broker může obsluhovat řadu klientů a jeden publisher může současně distribuovat data více odběratelům. 

MQTT běží nad protokolem TCP (Transmission Control Protocol), který zajišťuje spolehlivý přenos datových paketů. Zároveň má oproti jiným protokolům (například HTTP) výrazně nižší režii -- minimální velikost hlavičky je pouze 2 bajty \cite{MQTTvsCoAP}. Díky své jednoduchosti je vhodný i pro zařízení s~omezenými zdroji nebo nestabilním připojením. Protokol nabízí tři úrovně kvality doručení zpráv (Quality of Service, QoS). Na nejnižší úrovni QoS~0 je zpráva odeslána nejvýše jednou bez potvrzení (best-effort delivery), jedná se o~nejrychlejší variantu, která však nezaručuje doručení zprávy. QoS~1 zaručuje, že bude zpráva doručena alespoň jednou, broker čeká na potvrzení o~přijetí zprávy od příjemce. Nevýhodou je možný výskyt duplicitních zpráv. QoS~2, která tvoří nejvyšší úroveň, zaručuje doručení každé zprávy právě jednou. K~tomu využívá čtyřkrokového mechanismu potvrzení mezi odesílatelem a příjemcem \cite{MQTT-QoS}. Volba úrovně tak vždy představuje kompromis mezi spolehlivostí a energetickou náročností. Pro periodické odesílání senzorových dat u~monitoringu úlů si obvykle vystačíme s~QoS~0, případně QoS~1. 

Ve výchozím nastavení MQTT přenáší veškerá data včetně přihlašovacích údajů v~otevřené podobě, což představuje bezpečnostní riziko. Standardním řešením je provoz nad~protokolem TLS (Transport Layer Security), který zajišťuje šifrování komunikace mezi klientem a brokerem. Pro autentizaci klientů se běžně používá kombinace uživatelského jména a hesla, případně certifikáty \cite{MQTTsecurity}.

Mezi nejrozšířenější open-source MQTT brokery patří Eclipse Mosquitto, vhodný pro~lokální nebo vestavné systémy využívající například platformu Raspberry Pi, a EMQX určený pro rozsáhlejší cloudové nasazení. V~oblasti monitorování včelích úlů je protokol hojně využíván, například v~systémech \textit{Beemon} \cite{Beemon2021} či \textit{Bee Health Monitor} \cite{Nevlacil2023}.

\subsubsection*{HTTP}
HTTP (Hypertext Transfer Protocol) je nejrozšířenější komunikační protokol webu, založený na modelu \textit{request-response}: klient vysílá dotaz na server a čeká na odpověď. Každý požadavek je zcela nezávislý (protokol je bezstavový) a obsahuje relativně velkou režii. Základní varianta HTTP nepoužívá šifrování, proto se v~praxi využívá zejména jeho zabezpečená varianta HTTPS, která využívá protokol TLS.

Pro IoT aplikace s~malými a často opakovanými přenosy dat představuje tato režie nevýhodu oproti jiným protokolům, jakými jsou MQTT nebo CoAP. HTTP je nicméně ideální volbou tam, kde IoT zařízení komunikuje s~existující webovou infrastrukturou, například prostřednictvím REST API, cloudových služeb nebo webových rozhraní \cite{MQTTvsHTTP}. 

\subsubsection*{CoAP}
CoAP (Constrained Application Protocol) byl navržen jako odlehčená alternativa HTTP pro zařízení s~omezenými zdroji (mikrokontroléry s~malou pamětí) a nízkopříkonové sítě (například 6LoWPAN). Na rozdíl od MQTT používá transportní protokol UDP (User Datagram Protocol), což snižuje režii a umožňuje podporu multicastu. Nevýhodou je absence spolehlivosti na transportní vrstvě, která je však částečně řešena na aplikační úrovni pomocí potvrzovaných zpráv. 

CoAP používá obdobnou sémantiku jako HTTP (metody GET, POST, PUT, DELETE), díky čemuž je snadno integrovatelný do stávající webové infrastruktury. Pro zabezpečení komunikace nelze kvůli UDP využít protokolu TLS, místo něj se využívá protokol DTLS (Datagram Transport Layer Security). DTLS poskytuje šifrování i autentizaci, je však méně rozšířený a jeho implementace bývá složitější než u~TLS \cite{rfc7252}.

\subsubsection*{ESP-NOW}
ESP-NOW je komunikační protokol vyvinutý společností Espressif pro mikrokontroléry rodiny ESP8266 a ESP32. Na rozdíl od výše zmíněných protokolů nevyužívá TCP/IP stack, ale operuje přímo na úrovni Wi-Fi MAC vrstvy, čímž obchází celý síťový zásobník a dosahuje velmi nízké latence a spotřeby energie \cite{esp-now}. 

Komunikace probíhá přímo mezi zařízeními typu peer-to-peer bez nutnosti použití přístupového bodu nebo routeru. Jednotlivá zařízení jsou identifikována pomocí MAC adres. Tento přístup je vhodný zejména pro lokální bezdrátové sítě s~nízkými nároky na~infrastrukturu. Počet komunikujících zařízení je omezen typicky na 20 uzlů, při šifrované komunikaci 17 \cite{esp-nowDoc}. ESP-NOW je proto vhodný především pro menší lokální systémy, kde je klíčová nízká spotřeba, rychlá odezva a jednoduchá implementace.

\begin{table}[H]
    \centering
    \begin{tabular}{|c|c|c|c|c|c|}
    \hline
        \textbf{Protokol} & \textbf{Transport} & \textbf{Režie} & \textbf{Latence} & \textbf{Spolehlivost} & \textbf{Zabezpečení} \\
        \hline
        MQTT & TCP & nízká & nízká & vysoká & TLS \\
        \hline
        HTTP & TCP & vysoká & střední & vysoká & TLS (HTTPS) \\
        \hline
        CoAP & UDP & velmi nízká & velmi nízká & střední & DTLS \\
        \hline
        ESP-NOW & Wi-Fi MAC & velmi nízká & velmi nízká & nízká & AES-128 \\
        \hline
    \end{tabular}
    \caption{Porovnání komunikačních protokolů pro IoT.}
    \label{tab:porovnani_komunikace}
\end{table}

\chapter{Strojové učení a počítačové vidění, detekce anomálií}\label{sec:strojove_uceni}
Tato kapitola se zabývá využitím metod strojového učení a počítačového vidění pro analýzu dat získaných ze sledování včelstev. Nejprve jsou představeny základní principy strojového učení a jeho aplikace v~oblasti včelařství, zejména pro automatickou interpretaci senzorových dat. Dále je kapitola zaměřena na práci s~časovými řadami, které tvoří významnou část dat získaných z~monitorovacího systému. Jsou diskutovány přístupy k~jejich analýze, modelování a predikci. Součástí kapitoly jsou rovněž metody detekce anomálií umožňující automatické rozpoznání nestandardních stavů včelstva na základě naměřených dat. Závěrečná část je věnována počítačovému vidění, které -- na rozdíl od senzorového monitoringu -- umožňuje přímou vizuální analýzu dění na česně úlu, včetně detekce a sledování pohybujících se objektů a jejich klasifikace. Cílem kapitoly je vytvořit teoretický základ pro analytickou vrstvu navrženého systému.

\section{Strojové učení ve včelařství}
Strojové učení (Machine Learning, ML) je odvětvím umělé inteligence, v~němž algoritmy automaticky odvozují pravidla a vzory přímo z~dat, aniž by bylo nutné je explicitně programovat \cite{ML-IBM}. Na rozdíl od klasické prahové analýzy -- kdy včelař nebo programátor ručně nastaví mezní hodnoty (například pokud hmotnost klesne o~X, znamená to rojení) -- je ML model schopen zachytit složité, nelineární závislosti mezi proměnnými a adaptovat se na~specifika konkrétního úlu nebo stanoviště. V~kontextu monitorování včelstev to umožňuje přecházet od přístupu, kdy je problém detekován až po vzniku, k~přístupu proaktivnímu, při němž systém identifikuje varovné signály, než samotný problém nastane \cite{Sabic2025}.

Úlohy, které lze pomocí strojového učení ve včelařství řešit, lze rozdělit do několika kategorií. \textit{Klasifikace} přiřazuje vstupní data do předem definovaných tříd -- například umožňuje rozlišení zdravého a napadeného včelstva na základě senzorových dat nebo zvukového záznamu. \textit{Regrese} předpovídá spojité hodnoty, typicky budoucí hmotnost úlu nebo teplotu. \textit{Detekce anomálií} identifikuje odchylky od očekávaného chování bez nutnosti předem definovat, co přesně anomálie představuje. Tento přístup je vhodný pro zachycení neobvyklých událostí jako rojení, krádež nebo nástup choroby \cite{Sabic2025}.

Strojové učení se dále dělí podle dostupnosti označených trénovacích dat. \textit{Učení s~učitelem} (supervised learning) pracuje s~datasetem, kde je každý vstupní vzorek opatřen správnou odpovědí (labelem) \cite{ML-IBM}. Příkladem může být zvukový záznam označený jako rojení. Výhodou je vysoká přesnost a jasně měřitelná výkonnost modelu. Nevýhodu pak představuje náročnost anotace dat, která je ve včelařském kontextu obzvláště pracná, protože vyžaduje odborné posouzení zkušeného včelaře.

\textit{Učení bez učitele} (unsupervised learning) pracuje s~neoznačenými daty a hledá v~nich skryté struktury -- typicky shluky podobných stavů nebo odlehlé hodnoty indikující anomálii \cite{ML-IBM}. Tento přístup je výhodný právě tam, kde anotace dat není reálná, ale výsledky jsou obtížněji interpretovatelné a ověřitelné.

Specifické výzvy, které data z~monitorování úlů ML systémům přinášejí, jsou dobře zdokumentovány v~literatuře \cite{Sabic2025} a \cite{Turyagyenda2025}. Senzorová data jsou ze své podstaty časovými řadami s~výraznou sezónností, denními cykly a obsahují chybějící hodnoty způsobené výpadky zařízení. Kvalita dat se liší v~závislosti na umístění senzoru v~úlu. Kromě toho jsou datasety ve včelařství historicky malé. Navzdory zmiňovaným omezením výzkum v~této oblasti výrazně zesílil. ML modely prokázaly slibné výsledky napříč celým spektrem úloh, od predikce hmotnosti přes detekci varroázy až po předpověď rojení \cite{Sabic2025}.

\section{Práce s~časovými řadami}
Časová řada je posloupnost hodnot měřených v~pravidelných časových intervalech. Data ze~senzorů včelího úlu tvoří časové řady přirozeně: teplota v~úlu, relativní vlhkost, hmotnost a počet průletů česnem jsou zaznamenávány kontinuálně. Tato data nesou bohatou informaci o~stavu kolonie, avšak jsou zatížena šumem, výpadky způsobenými přerušením napájení nebo ztrátou konektivity, a jejich charakter se výrazně mění v~závislosti na ročním období nebo fázi vývoje kolonie \cite{Turyagyenda2025}.

Klíčovým prvním krokem při práci s~časovými řadami je jejich dekompozice, tj. rozložení na základní složky, kterými jsou \textit{sezónnost} \(S_t\), \textit{trend} \(T_t\) a \textit{rezidua} \(R_t\), a to vše v~čase \(t\). Existují dva přístupy: 

\begin{itemize}
    \item aditivní: \(y_t = S_t + T_t + R_t\)
    \item multiplikativní: \(y_t = S_t \times T_t \times R_t\)
\end{itemize}

Výběr mezi nimi závisí na tom, jestli se sezónní nebo reziduální vlivy mění úměrně trendu \cite{Hyndman2018}. Ten zachycuje dlouhodobý vývoj, například postupný pokles hmotnosti úlu v~zimním období způsobený spotřebou zásob. Sezónnost popisuje pravidelně se opakující vzory v~pevně daných intervalech. Ta se v~úlu projevuje jak na roční úrovni (aktivní období, zimní klid), tak na denní úrovni (ranní opouštění úlu, večerní návrat). Rezidua pak tvoří zbytkovou složku po odečtení trendu a sezónnosti -- náhodné výkyvy, ale i skutečné anomálie, jako je nemoc nebo rojení \cite{McMinnSauder2024}.

Důležitou vlastnost, kterou je třeba před modelováním ověřit, představuje \textit{stacionarita} časové řady -- tedy stav, kdy statistické vlastnosti (střední hodnota, směrodatná odchylka, rozptyl) nezávisí na čase \cite{Kulyukin2025}. Studie Kulyukin et al. \cite{Kulyukin2025} pracující s~daty hmotnosti a vnitřní teploty z~deseti kolonií ve výzkumném centru Bee Research Center v~Arizoně (monitorování probíhalo v~období červen--říjen 2022) zjistila, že tyto řady nejsou bílým šumem, nejsou normálně distribuované a navíc u~většiny úlů nebyla splněna podmínka stacionarity. K~jejímu zjištění se používají statistické testy: rozšířený Dickeyův-Fullerův test (ADF) testuje přítomnost jednotkového kořene, zatímco Kwiatkowski-Phillips-Schmidt-Shin test (KPSS) ověřuje stacionaritu daného řádu kolem deterministického trendu \cite{Kulyukin2025}. Pokud řada není stacionární, lze ji transformovat diferencováním (odečtením předchozí hodnoty od aktuální) nebo sezónním diferencováním v~případě přítomnosti sezónní složky.

\subsection*{Modely pro práci s~časovými řadami}
Mezi nejrozšířenější statistické modely se řadí rodina modelů \textit{ARIMA} (AutoRegressive Integrated Moving Average). Vyniká ve zpracování jednorozměrných dat, ale lze ji upravit i pro~datasety s~vícerozměrnými daty. Model je definován třemi parametry: \(p\), \(d\), \(q\). Parametr~\(p\) představuje řád autoregresní části, tedy počet minulých datových bodů použitých k~předpovědi, \(d\) odpovídá míře diferenciace potřebné k~dosažení stacionarity a \(q\) řádu klouzavého průměru \cite{ML-IBM}. Model předpokládá lineární vztahy, jeho předností jsou krátkodobé předpovědi a výpočetní nenáročnost. Nevýhody pak spočívají v~neschopnosti zachycovat nelineární závislosti a nutnosti ruční volby parametrů \cite{Yadav2022}. Pro data s~výraznou sezónností se používá varianta \textit{SARIMA}, která přidává sezónní složku danou parametry \((P, D, Q, S)\). \(P\), \(D\), \(Q\) představují sezónní ekvivalenty parametrů \(p\), \(d\), \(q\). \(S\) označuje délku sezónního cyklu. Studie Kulyukin et al. \cite{Kulyukin2025} prokázala, že modely SARIMA konzistentně překonávají standardní ARIMA při predikci hmotnosti a teploty úlů, přičemž optimální parametry jsou specifické pro každou kolonii a nelze je jednoduše přenášet mezi úly. Zároveň ukazuje, že hmotnost poskytovala přesnější výsledky než teplota. Také existuje verze, která dokáže pracovat s~vícerozměrnými daty, kterými právě úlová data jsou, a tou je \textit{VARMAX} \cite{ML-IBM}.

Alternativu představuje model \textit{Prophet} -- open-source framework vyvinutý společností Meta, který přistupuje k~časové řadě jako k~součtu složek trendu, sezónnosti a efektů svátků nebo výjimečných událostí \cite{Yadav2022}. Prophet je navržen tak, aby si poradil s~chybějícími hodnotami a nestacionaritou, automaticky detekoval zlomové body v~trendu a snadno zvládal vícenásobnou sezónnost (roční i denní zároveň) bez nutnosti hlubší znalosti statistiky ze~strany uživatele. Hlavní výhodou oproti modelům ARIMA je větší robustnost vůči chybějícím datům (například při výpadcích zařízení) \cite{Taylor2018}. Nevýhodou je pak horší výkon na~krátkých horizontech předpovědi a menší interpretovatelnost jednotlivých parametrů \cite{Yadav2022}.

Dalším přístupem jsou rekurentní neuronové sítě (RNN), zejména architektura \textit{LSTM} (Long short-term memory). LSTM je speciální typ rekurentní neuronové sítě navržený tak, aby překonával neschopnost klasických RNN učit se dlouhodobé závislosti v~sekvenčních datech. Síť je tvořena vrstvami paměťových buněk vybavených třemi řídicími branami: \textit{vstupní} brána (input gate) rozhoduje, které nové informace budou uloženy do paměti, brány \textit{zapomínání} (forget gate) určuje, které informace z~předchozích kroků budou zahozeny a \textit{výstupní} (output gate) kontroluje, co z~paměti bude předáno jako výstup \cite{Gers2000}. Díky tomuto mechanismu je LSTM schopen zachovat relevantní kontext přes stovky časových kroků a zachytit nelineární závislosti, které statistické modely přehlédnou. Mezi přednosti LSTM patří vysoká prediktivní přesnost na komplexních vzorech. Nevýhodou je výrazně vyšší datová  i výpočetní náročnost \cite{Yadav2022}. V~kontextu včelařství je LSTM vhodný spíše pro rozsáhlejší monitorovací sítě s~dlouhodobým provozem, kde je k~dispozici dostatek historických dat z~více úlů.

Odlišný přístup oproti statistických modelů i hlubokých neuronových sítí představují metody \textit{gradientního boostingu}, konkrétně model \textit{LightGBM} (Light Gradient Boosting Machine). Jedná se o~framework pro trénování rozhodovacích stromů vyvinutý společností Microsoft, který oproti tradičním implementacím gradientního boostingu využívá dvě klíčové optimalizační techniky -- \textit{Gradient-based One-Side Sampling} (GOSS) a \textit{Exclusive Feature Bundling} (EFB) -- díky nimž dosahuje až dvacetinásobně rychlejšího trénování při~zachování srovnatelné přesnosti \cite{Ke2017}. Pro práci s~časovými řadami se LightGBM nepoužívá přímo jako sekvenční model, ale prostřednictvím tzv. \textit{feature engineeringu}: ze surových dat jsou odvozeny zpožděné hodnoty, klouzavé průměry a statistiky v~posuvném okně. Dokáže si také dobře poradit s~chybějícími hodnotami. Ve srovnání s~LSTM je výpočetně méně náročný a jeho výsledky jsou lépe interpretovatelné, například pomocí hodnot důležitosti příznaků (feature importance) nebo metody SHAP. V~kontextu včelařství jej výzkumnice \cite{Luca2025} nasadily pro detekci přítomnosti matky ze senzorových dat teploty, vlhkosti a tlaku.

\subsection*{Metriky hodnocení modelů}
Pro porovnání kvality předpovědí modelů časových řad se používají standardní regresní metriky. \textit{Mean absolute error} (MAE) vyjadřuje průměrnou absolutní odchylku předpovědi od~skutečné hodnoty a je méně citlivá na odlehlé hodnoty. \textit{Root mean squared error} (RMSE) chyby umocní a následně zprůměruje, tím penalizuje velké odchylky výrazněji než~MAE. \textit{Mean absolute percentage error} (MAPE) vyjadřuje chybu jako procento skutečné hodnoty, čímž je nezávislá na škále dat a umožňuje srovnávat modely napříč datasety. Je však nevhodná v~případech, kdy měřená veličina nabývá hodnot blízkých nule. \textit{Coefficient of determination} \(R^2\) vyjadřuje, jaký podíl variance dat model vysvětluje: hodnota blízko~1 znamená, že se předpovědi blíží skutečným hodnotám, naopak hodnota blízko~0 říká, že předpovědi nijak se skutečností nesouvisí \cite{Hyndman2018}.

\subsection*{Detekce anomálií}
Detekce anomálií (anomaly detection) představuje klíčovou úlohu při monitorování včelstev, protože umožňuje identifikovat neobvyklé chování kolonie bez nutnosti předem definovat nežádoucí stavy. V~kontextu časových řad se anomálie typicky projevují jako náhlé odchylky od očekávaného trendu nebo sezónního průběhu, případně jako změny v~dynamice signálu \cite{Chandola2009}.

Z~praktického hlediska lze anomálie rozdělit na několik typů. \textit{Bodové anomálie} (point anomalies) představují jednotlivé odlehlé hodnoty. \textit{Kontextuální anomálie} (contextual anomalies) jsou hodnoty neobvyklé pouze v~určitém kontextu (např. stejná hodnota teploty může být normální v~zimě, ale anomální v~létě). \textit{Kolektivní anomálie} (collective anomalies) tvoří skupiny datových instancí, které samostatně nemusí být anomální, ale jejich společný výskyt jako celek anomální je \cite{Chandola2009}.

Nejjednodušší přístup k~detekci anomálií představují metody založené na heuristických pravidlech a prahových hodnotách. Na základě pozorování historických dat se ručně stanoví maximální a minimální práh, přičemž každý bod překračující tento rozsah je označen za~anomální. Výhodou těchto metod je vysoký výkon v~reálném čase a snadná implementace vhodná například pro real-time monitorovací systémy. Jejich zásadní nevýhodou je však nutnost silné znalosti dat a také citlivost na jakékoliv změny dat způsobené například modernizací systému. U~vícerozměrných dat je navíc nutné nastavovat práh pro každou dimenzi zvlášť, čímž se snižuje použitelnost metody, a výsledkem je relativně vysoká míra falešně pozitivních i negativních detekcí \cite{Chen2022}.

Pokročilejší metody využívají modely strojového učení. V~případě \textit{model-based přístupů} se nejprve natrénuje predikční model (např. ARIMA, Prophet) a anomálie jsou detekovány jako výrazné rozdíly mezi predikovanou a skutečnou hodnotou. Tento přístup umožňuje zohlednit komplexní časové závislosti, avšak kvalita detekce je přímo závislá na přesnosti modelu \cite{Chen2022}.

Další skupinu tvoří metody \textit{učení bez učitele}, které nevyžadují označená data. Mezi nejpoužívanější patří algoritmy jako \textit{Isolation Forest}, který detekuje anomálie na základě jejich izolovatelnosti v~datovém prostoru \cite{Liu2008}, nebo \textit{Local Outlier Factor} (LOF), jenž porovnává hustotu okolí daného bodu s~hustotou jeho sousedů \cite{Chandola2009}. Tyto metody jsou vhodné zejména tam, kde není k~dispozici dostatek anotovaných dat, což je typický případ v~oblasti včelařství. Specifickou kategorii tvoří hluboké neuronové sítě, zejména \textit{autoenkodéry}, to jsou neuronové sítě trénované tak, aby co nejpřesněji rekonstruovaly vstupní data. Anomálie se projeví jako instance s~vysokou rekonstrukční chybou, protože model naučený na~normálním chování je nedokáže věrně reprodukovat. Výhodou tohoto přístupu je schopnost zachytit komplexní nelineární vztahy, nevýhodou pak vyšší výpočetní náročnost a obtížnější interpretace výsledků \cite{Chen2022}.

\section{Počítačové vidění}
Počítačové vidění (computer vision) je oblast umělé inteligence zabývající se automatickým porozuměním vizuálním datům. Základní úlohy zahrnují klasifikaci, detekci a segmentaci objektů. V~kontextu monitorování včelstev je nejrelevantnější detekce objektů, při níž jsou objekty v~obraze lokalizovány a klasifikovány pomocí ohraničujících boxů (bounding boxes). Moderní systémy počítačového vidění jsou téměř výhradně postaveny na konvolučních neuronových sítích (Convolutional Neural Networks, CNN), které představují specifický typ neuronových sítí využívaných v~hlubokém učení. Trénování CNN bývá velmi výpočetně náročné, proto se provádí například na specializovaných serverech s~GPU poskytujících dostatečný výkon. Na edge zařízení, například Raspberry Pi, se pak nasazuje pouze natrénovaný model v~optimalizované podobě. Hojně se také využívá již předtrénovaných modelů, ty se pak dotrénují pro konkrétní využití \cite{Bilik2024}.

Studie Bílík et al. \cite{Bilik2024}, která mapuje více než 50 výzkumných projektů zaměřených na automatizované metody monitorování včelstev pomocí počítačového vidění, identifikuje tři dominantní aplikační oblasti: detekci pylu a včel nesoucích pyl, detekci roztoče \textit{Varroa destructor} a letovou aktivitu u~česna. Zároveň dokumentuje jasný trend úpadku konvenčních metod počítačového vidění ve prospěch detektorů objektů a klasifikátorů na~bázi CNN. Tento vývoj koresponduje s~tím, co ve svém systematickém přehledu pozorují i Šabić~et~al.~\cite{Sabic2025}.

\subsection*{Modely pro detekci objektů} \label{sec:modely_detekce}
V~oblasti detekce objektů se rozlišují dvoufázové a jednofázové přístupy. Dvoufázové metody, jejichž typickým zástupcem je rodina \textit{R-CNN} (region-based convolutional neural network), nejprve generují návrhy oblastí a teprve poté je klasifikují a zpřesňují jejich ohraničení. Tento přístup dosahuje vysoké přesnosti, zejména u~malých nebo překrývajících se objektů, avšak za cenu vyšší výpočetní náročnosti a latence. Jednofázové detektory, především rodina \textit{YOLO} (You Only Look Once), zpracovávají celý obraz v~jediném průchodu sítí. Výsledkem jsou přímo souřadnice ohraničujících boxů a pravděpodobnosti tříd. Díky tomu dosahují vysoké rychlosti zpracování a nízké latence, což je činí vhodnými pro aplikace v~reálném čase \cite{ML-IBM}. Proto jsou jednofázové detektory standardní volbou pro vestavné systémy.

Rodina YOLO prošla od svého vzniku v~roce 2015 významným vývojem. Původní model YOLO byl postupně vylepšován, přičemž zásadní posun přinesly novější implementace jako YOLOv5 a zejména YOLOv8 vydané společností Ultralytics v~lednu 2023. Pro nasazení na vestavných systémech jsou klíčové odlehčené varianty modelů, označované jako \textit{nano} (YOLOv8n), případně \textit{tiny} u~starších verzí. Tyto modely jsou navrženy s~důrazem na~minimalizaci výpočetní náročnosti. Za cenu mírného snížení přesnosti poskytují dostatečný výkon pro detekci objektů v~reálném čase \cite{Krishnan2024}. V~kontextu monitorování včelstev lze modely YOLO využít zejména pro analýzu obrazu z~česna úlu. Typickými úlohami jsou detekce a počítání včel, rozlišení směru jejich pohybu (přílet/odlet) nebo identifikace predátorů (např. vosy) \cite{Bilik2024}. Společnost vyvinula ještě dva novější modely, kterými jsou YOLO11 a YOLO26~\cite{ultralytics}.

Vedle modelů rodiny YOLO existují i další jednofázové detektory, které jsou vhodné pro~real-time nasazení. Mezi nejvýznamnější patří model \textit{SSD} (Single Shot MultiBox Detector), který kombinuje principy rychlé detekce s~využitím více měřítek (multi-scale feature maps) \cite{Liu2016}. Model SSD, na rozdíl od YOLO, využívá několik vrstev neuronové sítě k~detekci objektů různých velikostí. Každá z~těchto vrstev detekuje objekty v~jiném měřítku, což zlepšuje schopnost modelu zachytit malé objekty. Díky tomu dosahuje vyšší přesnosti než starší verze YOLO při zachování vysoké rychlosti zpracování. Nevýhodou je však stále relativně vysoká výpočetní náročnost \cite{Liu2016}. Pro nasazení na edge zařízeních se často používá kombinace SSD s~lehkými backbone architekturami, například \textit{MobileNet}.

Specifickou kategorii představují modely typu \textit{FOMO} (Faster Objects, More Objects), které jsou navrženy přímo pro extrémně omezená vestavná zařízení, například mikrokontroléry či jednodeskové počítače. Na rozdíl od klasických detektorů objektů FOMO nevrací ohraničující boxy, ale využívá přístup založený na tzv. \textit{heatmaps}, v~nichž model predikuje pravděpodobnost výskytu objektu v~jednotlivých částech obrazu. Nevýhodou je nižší přesnost lokalizace a omezená schopnost rozlišovat překrývající se objekty \cite{fomo}. 

Volba vhodného modelu pro nasazení na RPi 5 vyžaduje zohlednění tří vzájemně provázaných faktorů: přesnosti detekce, doby inference a spotřeby energie. Studie Alqahtani et~al. \cite{Alqahtani2025} testovala modely YOLOv8 (Nano, Small, Medium), EfficientDet Lite (Lite0, Lite1, Lite2) a SSD (MobileNet V1, SSDLite MobileDet) na zařízeních RPi 3, 4, 5 s~TPU (Tensor Processing Unit) akcelerátorem i bez něj. Na zařízení Raspberry Pi 5 dosahoval nejlepších výsledků model MobileNetV1, nicméně nejvyšší přesnosti dosahovaly varianty modelu YOLOv8. Z~hlediska kompromisu mezi přesností a rychlostí se jako optimální volby pro~nasazení na Raspberry Pi 5 jeví právě nano varianty modelů YOLO.

\subsection*{Metriky vyhodnocování modelů počítačového vidění}
Hodnocení modelů pro detekci objektů je výrazně komplexnější než hodnocení klasifikátorů, protože model musí správně přiřadit nejen třídu, ale také samotný objekt ve snímku lokalizovat. Standardní sada metrik proto kombinuje měření lokalizační přesnosti, klasifikační přesnosti a jejich vzájemného kompromisu. Klíčovými pojmy jsou \textit{skutečně pozitivní detekce} (True Positive, TP), \textit{falešně pozitivní detekce} (False Positive, FP) a \textit{falešně negativní detekce} (False Negative, FN). TP značí detekce, při nichž model správně identifikoval objekt a jeho predikovaný ohraničující box dostatečně překrývá skutečný box (tzv. \textit{ground truth}). FP je detekce, pži níž model označil objekt, který buď neexistuje, nebo je ohraničující box příliš nepřesný. FN nastává v~případě, kdy model skutečný objekt nedetekuje vůbec \cite{Padilla2020}.

\textbf{Intersection over Union} (IoU) představuje základní metriku lokalizační přesnosti, která určuje míru překryvu mezi predikovaným ohraničujícím boxem \(B_p\) a referenčním boxem \(B_{gt}\):

\[IoU = \frac{S(B_p \cap B_{gt})}{S(B_p \cup B_{gt})}\]

Hodnota IoU se pohybuje v~rozmezí \(\langle0, 1\rangle\), přičemž 0 znamená nulový překryv a 1 znamená dokonalou shodu. IoU slouží jako prahová hodnota pro rozhodnutí, zda je detekce považována za TP nebo FP. Nejčastěji používaná hodnota prahu je \(IoU \geq 0{,}5\), při přísnějším hodnocení se používá \(IoU \geq 0{,}75\) nebo průměr přes rozsah prahů od 0,5 do 0,95 s~krokem o~velikosti 0,05 dle standardu benchmarku COCO \cite{Padilla2020}.

\begin{figure}[H]
	\centering
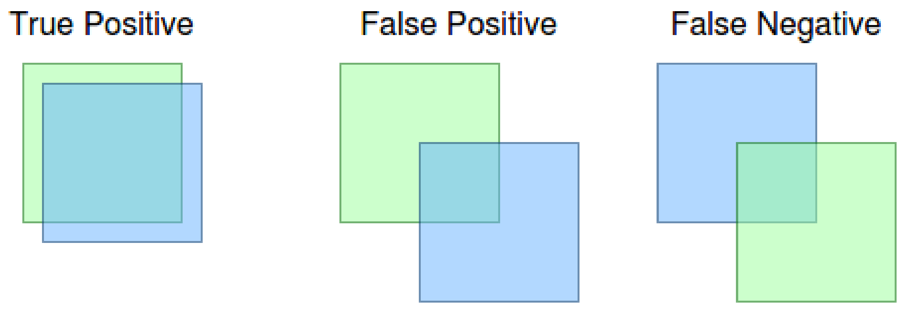
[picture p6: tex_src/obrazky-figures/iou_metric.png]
    
	\caption[Druhy detekce: skutečně pozitivní, falešně pozitivní a falešně negativní.]{Druhy detekce: skutečně pozitivní, falešně pozitivní a falešně negativní.\footnotemark}
	\label{fig:iou_metriky}
\end{figure}
\footnotetext{Obrázek pochází z~\cite{Bilik2021}, Obrázek 4.}

\textbf{Přesnost} (Precision, P) vyjadřuje, jaká část všech provedených detekcí byla správná, tedy kolik z~predikovaných objektů skutečně existuje.

\[P = \frac{TP}{TP + FP}\]

\textbf{Úplnost} (Recall, R) vyjadřuje, jaká část všech reálných objektů v~obraze byla detekována, tedy jak moc je model schopen zachytit vše, co existuje.

\[R = \frac{TP}{TP + FN}\]

Tyto dvě metriky jsou vzájemně provázány: se zvyšujícím se prahem spolehlivosti (confidence threshold) roste přesnost detekce, zatímco úplnost klesá, protože model odmítá méně jisté predikce. Naopak snížení prahu vede k~vyšší úplnosti za cenu nárůstu FP detekcí. Práh spolehlivosti představuje minimální hodnotu pravděpodobnosti (confidence score), kterou model přiřazuje detekovanému objektu. Pouze detekce s~hodnotou vyšší než tento práh jsou považovány za platné a zahrnují se do výsledku \cite{Padilla2020}. Proto hodnota prahu závisí na konkrétním použití, například v~kontextu detekce kleštíka je vhodné preferovat vyšší úplnost (tedy nižší práh spolehlivosti), jelikož přehlédnutí přítomnosti roztoče představuje větší riziko než~falešný poplach \cite{Bilik2021}.

\textbf{F1 skóre} je harmonickým průměrem přesnosti a úplnosti a poskytuje jednu souhrnnou hodnotu, která nabízí komplexnější vhled do vyhodnocení výkonu modelu.

\[F_1 = 2 \cdot \frac{P \cdot R}{P + R}\]

Harmonický průměr (na rozdíl od aritmetického) penalizuje situace, kdy je jedna z~hodnot výrazně nižší. F1 skóre je zvláště užitečné pro srovnání modelů při daném pevném prahu spolehlivosti a je standardní metrikou v~aplikacích detekce včel a Varroa, kde studie typicky reportují F1 při IoU@0.5 \cite{Bilik2021}.

\textbf{Průměrná přesnost} (Average Precision, AP) agreguje výkon modelu přes celý rozsah hodnot prahu spolehlivosti. Počítá se jako plocha pod křivkou přesnosti a úplnosti (Precision–Recall curve). Každý bod na křivce odpovídá jedné hodnotě prahu spolehlivosti.

\textbf{Střední průměrná přesnost} (mean Average Precision, mAP) je průměrem AP přes všechny třídy objektů v~datové sadě.

\[mAP = \frac{1}{N} \sum_{i = 1}^N AP_i\]

kde \(N\) představuje počet tříd. Hodnota mAP@0.5 představuje mAP při pevném IoU prahu~0,5 a je nejčastěji využívanou metrikou v~literatuře zaměřené na monitorování včelstev \cite{Bilik2021}. 

Pro nasazení na edge zařízeních jsou vedle přesnostních metrik klíčové také metriky výpočetní efektivity. \textbf{Snímková frekvence} (Frames Per Second, FPS) udává, kolik snímků je model schopen zpracovat za sekundu, a tím určuje, zda je aplikace schopna real-time provozu dosáhnout. \textbf{Latence} (inference time) označuje dobu potřebnou ke zpracování jednoho snímku v~milisekundách.

\chapter{Zhodnocení současného stavu a návrh řešení} \label{sec:zhodnoceni_navrh}
Předchozí kapitoly ukázaly, že oblast monitorování včelstev disponuje jak rozvinutým komerčním trhem, tak aktivní akademickou základnou. Cílem kapitoly je tato dvě prostředí kriticky porovnat, identifikovat potřeby, které dosud nebyly uspokojeny, a na základě tohoto rozboru formulovat cíle a návrh vlastního řešení.

Komerční produkty jsou obecně na vysoké úrovni z~hlediska hardwarového zpracování i uživatelského rozhraní. Váhy od VeluBee, BeeSage nebo BeeHiveMonitoring jsou robustní, snadno instalovatelné a nabízejí přehledné webové nebo mobilní aplikace s~detekcí základních událostí, jako jsou rojení nebo loupež. Tyto vlastnosti jsou pro běžného včelaře zásadní a je vhodné je zohlednit i ve vlastním návrhu. 

Přesto mají téměř všechna komerční řešení dva společné nedostatky. Prvním je absence automatické vizuální analýzy česna -- mechanické čítače včel, například od BeeHiveMonitoring, sice umožňují sledovat počet průchodů, avšak nedokáží jednotlivé jedince rozlišit ani klasifikovat. Včelař tak nemůže být automaticky upozorněn například na přítomnost predátora. Druhým nedostatkem je uzavřenost těchto systémů: zdrojový kód ani použité analytické metody nejsou veřejně dostupné. Včelař je tak závislý na konkrétním výrobci a jeho cloudové infrastruktuře, často i na placeném předplatném. Oba tyto nedostatky představují příležitost, kterou se tato práce snaží využít.

Z~akademické sféry jsou pro tuto práci relevantní zejména dva projekty. Systém Beemon \cite{Beemon2021} z~Appalachian State University kombinuje senzorový monitoring (teplota, vlhkost, hmotnost) s~audiovizuálními záznamy z~česna na platformě Raspberry Pi 4 a zasílá upozornění prostřednictvím IoT platformy ThingsBoard. Klíčovým omezením je však způsob zpracování obrazu: místo moderních detektorů objektů (např. YOLO nebo SSD) autoři segmentují včely na základě jejich obrysů, což je přístup citlivý na změny osvětlení a překryvy jedinců.

Druhým relevantním projektem je práce Nevláčila, Bilíka a Horáka z~VUT v~Brně \cite{Nevlacil2023}, zaměřená na detekci roztočů \textit{Varroa destructor} pomocí počítačového vidění v~kombinaci se senzorovým monitoringem. Na rozdíl od~systému Beemon využívá moderní přístup k~detekci objektů a přenáší data protokolem MQTT, což z~něj činí bližší referenci pro tuto práci. Systém je postaven na platformě Raspberry Pi a vyznačuje se modulární architekturou a využitím standardních IoT technologií. Zároveň však vyžaduje relativně výkonný hardware a stabilní komunikační infrastrukturu, což může být limitující při nasazení v~odlehlých lokalitách.

Oba systémy navíc ukazují, že platforma Raspberry Pi je schopna zvládat náročnější real-time úlohy, jako je zpracování videa, a že 3D tisk představuje dostupný a flexibilní způsob výroby mechanických částí na míru.

\section{Srovnání použitých technologií a jejich omezení}
Z~hlediska použitých technologií lze současná řešení rozdělit do tří základních kategorií podle způsobu získávání informací o~stavu včelstva. 

Základ většiny systémů tvoří senzorový monitoring fyzikálních veličin -- zejména hmotnosti úlu, teploty a vlhkosti. Výhodou je relativní jednoduchost, nízká energetická náročnost a vysoká spolehlivost dlouhodobého provozu. Nevýhodou je nepřímý charakter informací. Například pokles hmotnosti signalizuje možné rojení, ale nedokáže jej potvrdit ani odlišit od jiných příčin.

Druhou kategorii tvoří akustické systémy analyzující zvuk uvnitř úlu. Umožňují zachytit změny v~chování včelstva dříve, než  se projeví v senzorových datech, například při přípravě na rojení. Jejich nevýhodou je vyšší citlivost na šum prostředí a složitější interpretace signálu vyžadující specializované metody zpracování. 

Nejpokročilejší přístup představují systémy využívající počítačové vidění. Na rozdíl od senzorového monitoringu umožňují přímo analyzovat dění na česně -- detekovat a klasifikovat jedince, sledovat směr jejich pohybu nebo identifikovat predátory. Právě tato schopnost představuje informační hodnotu, kterou senzory ani akustické systémy nedokáží nahradit. Nevýhodou je výrazně vyšší výpočetní náročnost, potřeba kvalitního a stabilního osvětlení a nutnost robustních modelů schopných pracovat v~proměnlivých venkovních podmínkách.

Z~pohledu hardwaru a komunikačních technologií je patrný rozdíl mezi komerčními a akademickými řešeními. Komerční produkty staví na energeticky úsporných mikrokontrolérech a specializovaných deskách plošných spojů (PCB) optimalizovaných pro konkrétní aplikaci, přičemž komunikaci zajišťují mobilní sítě nebo nízkoenergetické protokoly umožňující vzdálený přístup k~datům. To přináší uživatelský komfort, avšak za cenu závislosti na výrobci a jeho infrastruktuře. Akademické projekty naopak preferují univerzální platformy jako Raspberry Pi, které usnadňují rychlé prototypování a implementaci pokročilých algoritmů, avšak za cenu vyšší spotřeby energie.

Z~tohoto srovnání vyplývají dvě klíčová zjištění pro návrh vlastního řešení. Za prvé, žádná z~kategorií sama o~sobě neposkytuje úplný obraz o~stavu včelstva -- teprve kombinace senzorového monitoringu s~počítačovým viděním přináší jak dlouhodobý kontextový pohled, tak schopnost identifikovat konkrétní události na česně. Za druhé, výhody komerčních řešení (robustnost, jednoduchost nasazení) a akademických projektů (otevřenost, flexibilita) se vzájemně doplňují a jejich propojení představuje přirozenou motivaci pro vlastní návrh popsaný v~následujících sekcích.

\section{Navázání na předchozí práci} \label{sec:navazani}
Tato práce navazuje na bakalářskou práci Bc. Kataríny Chovancové \cite{Chovancova2025}, která se zabývala návrhem a realizací kamerového systému pro monitorování dění na letáku úlu. Základ systému tvoří jednodeskový počítač Raspberry Pi 5, pro analýzu obrazu je využíván model počítačového vidění YOLOv8n, schopný detekovat tři třídy: včelu, včelí matku a vosu. Naměřená data jsou přenášena prostřednictvím mobilního datového připojení na IoT platformu ThingsBoard, napájení zajišťuje baterie se solárním panelem. 

Přestože uvedený systém představuje funkční základ pro vizuální monitorování česna, má klíčové omezení. Zaměřuje se výhradně na obrazová data z~česna a neposkytuje žádné informace o~fyzikálním stavu včelstva uvnitř úlu. 

Cílem navrhovaného řešení je toto omezení překonat a vytvořit komplexnější monitorovací řešení kombinující více zdrojů informací. Konkrétně jde o~doplnění senzorového modulu měřícího hmotnost úlu, teplotu a vlhkost, které umožňují dlouhodobé sledování stavu včelstva. Součástí řešení je rovněž integrace kamerového systému z~předchozí práce do nově navržené architektury. 

\begin{figure}[H]
    \centering
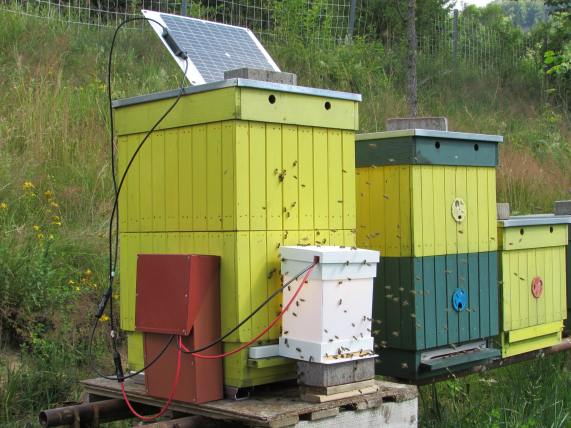
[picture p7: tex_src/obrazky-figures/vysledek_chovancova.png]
    
    \caption{Výsledná podoba zařízení Bc. Kataríny Chovancové \cite{Chovancova2025}.}
    \label{fig:vysledek_chovancova}
\end{figure}

\section{Návrh systému a výběr materiálů}
Navrhovaný systém pro monitorování včelstev se skládá ze dvou vzájemně nezávislých, ale komplementárních modulů: senzorového pro měření hmotnosti, teploty a vlhkosti a kamerového pro vizuální analýzu česna. Oba moduly jsou navrženy jako samostatně funkční celky, které lze nasadit nezávisle nebo kombinovat. Tato modularita je vědomou volbou oproti komerčním řešením, kde bývají senzory vázány na proprietární hub nebo cloudovou infrastrukturu konkrétního výrobce. Celý systém je open-source a veškerý kód i návrh konstrukce jsou veřejně dostupné v repozitáři na platformě GitHub\,\footnote{\url{https://github.com/e-kreme/Robotic-Beekeeper}}.

Požadavky na systém vycházejí z~analýzy komerčních řešení, odborné literatury a praktických včelařských zkušeností:

\begin{itemize}
    \item zajištění celoročního provozu v~proměnlivých venkovních podmínkách
    \item dostatečná přesnost měření umožňující detekci relevantních událostí ve včelstvu (např. snůška, rojení, úhyn)
    \item využití cenově dostupných komponent s~ohledem na výslednou cenu zařízení
    \item jednoduchá instalace bez nutnosti zásadních zásahů do konstrukce úlu
    \item průběžný sběr a zpracování dat s~přehlednou vizualizací, včetně možnosti lokálního zobrazení přímo na zařízení
    \item minimalizace vlivu systému na přirozené chování včelstva
\end{itemize}

\subsection*{Návrh architektury systému}
Architektura systému odráží přirozené rozdělení rolí jednotlivých komponent. Senzorový modul postavený na mikrokontroléru ESP32-S3 průběžně měří fyzikální veličiny charakterizující stav včelstva (podrobněji viz sekce \ref{sec:veliciny}) -- konkrétně hmotnost úlu, venkovní teplotu a vnitřní podmínky v~úlu (teplotu, vlhkost a tlak).

Data jsou průběžně zpracovávána a následně přenášena prostřednictvím bezdrátové komunikace do vzdáleného úložiště pro další analýzu a vizualizaci. Data jsou odesílána prostřednictvím protokolu MQTT, který je pro IoT aplikace tohoto typu standardní volbou \cite{Beemon2021}, \cite{Nevlacil2023}, \cite{Chovancova2025}, na Raspberry Pi 4 sloužící jako centrální úložiště. Kamerový modul s~Raspberry Pi 5 zpracovává obrazová data z~česna lokálně a výsledky vizuální analýzy jsou integrovány se senzorovými záznamy. Vzdálený přístup k~datům je zajištěn prostřednictvím VPN sítě Tailscale. Napájení senzorového modulu zajišťuje baterie v~kombinaci se solárním panelem, kamerový modul je napájen ze sítě.

Z~hlediska softwaru je firmware senzorového modulu vyvíjen v~prostředí Arduino IDE, které poskytuje přímou podporu pro použité senzory a komunikační protokoly. Zpracování a analýza dat probíhá v~jazyce Python. Pro vizualizaci časových průběhů měřených veličin je využita platforma Grafana, která umožňuje přehledné zobrazení dat a jejich vzdálenou správu.

\subsection*{Návrh konstrukce úlové váhy}
Základním prvkem senzorového modulu je konstrukce úlové váhy určená pro dlouhodobé a spolehlivé měření hmotnosti úlu v~reálných venkovních podmínkách. Klíčovým konstrukčním rozhodnutím je volba počtu a rozmístění váhových senzorů, přičemž v~praxi se lze setkat se třemi přístupy.

Nejjednodušší je hranový způsob vážení, kdy je jedna hrana úlu podložena váhou a naměřená hodnota se zdvojí za předpokladu symetrického rozložení hmotnosti úlu. Tento přístup je cenově nenáročný, avšak nepřesný -- rozložení hmotnosti v~úlu se v~průběhu roku mění v~závislosti na tvorbě a spotřebě zásob. Druhým přístupem jsou váhy se dvěma nebo čtyřmi senzorovými buňkami, například od BeeSage nebo BeeHiveMonitoring, které nezávisí na centrickém umístění zátěže. Nevýhodou je vyšší cena a náročnější kalibrace, protože každá buňka musí být kalibrována zvlášť.

Pro tuto práci jsem zvolila třetí přístup -- jedinou centrální váhovou buňku, stejně jako u~systému VeluBee. Úl je uložen na rámové nosné konstrukci a váhový senzor je umístěn mezi dvěma mechanicky oddělenými částmi rámu, čímž je zatížení přenášeno přímo na měřicí prvek. Toto uspořádání zachovává dostatečnou mechanickou stabilitu a zároveň zjednodušuje kalibraci.

\begin{figure}[H]
    \centering
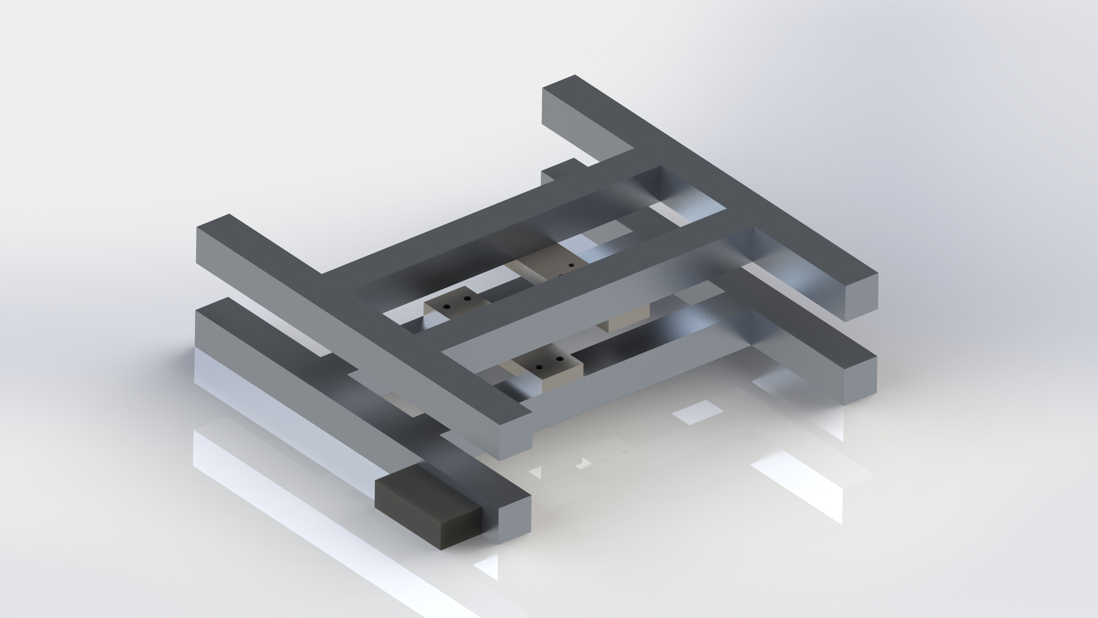
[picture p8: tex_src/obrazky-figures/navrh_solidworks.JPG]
    
    \caption{3D model konstrukce úlové váhy.}
    \label{fig:navrh_solidworks}
\end{figure}

Konstrukce byla navržena v~prostředí SolidWorks (viz obrázek \ref{fig:navrh_solidworks}) a přizpůsobena rozměrům domácího úlu 46 $\times$ 46 cm. Pro ověření mechanické odolnosti byla v~prostředí ANSYS Workbench 2025 R2 provedena simulace zatížení 100 kg (viz obrázek \ref{fig:simulace_zatizeni}). Maximální celková deformace dosáhla přibližně $1{,}4 \times 10^{-4}$ m (0,14 mm) na okrajích horní části konstrukce, přičemž tato hodnota je vzhledem k~rozměrům konstrukce zanedbatelná a na přesnost měření nemá vliv. Simulace neodhalila žádná kritická místa ohrožující mechanickou integritu systému.

\begin{figure}[H]
    \centering
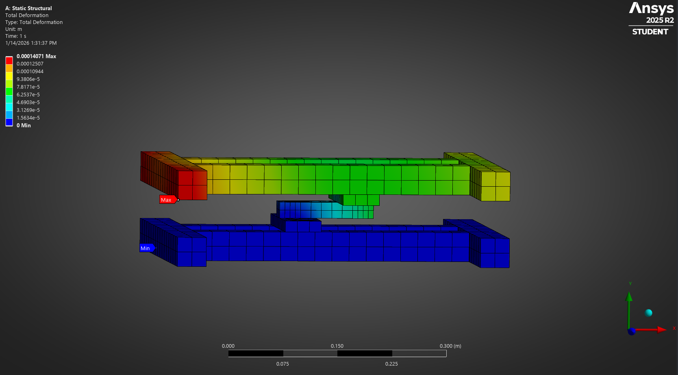
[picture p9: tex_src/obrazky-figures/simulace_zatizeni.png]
    
    \caption{Simulace zatížení vytvořeného modelu konstrukce hmotností 100 kg.}
    \label{fig:simulace_zatizeni}
\end{figure}

\subsection*{Výběr materiálu konstrukce}
Jako konstrukční materiál jsem zvolila standardizované hliníkové profily, které představují vhodný kompromis mezi hmotností, pevností a odolností vůči vnějším vlivům. Klíčovou vlastností je vysoká odolnost hliníku vůči korozi, a to i při mechanickém poškození povrchu, což je zásadní pro dlouhodobý provoz ve venkovním prostředí s~proměnlivou vlhkostí a teplotou. Ve srovnání s~ocelí má hliník nižší modul pružnosti, avšak jak dokládá výše uvedená simulace, výsledné deformace jsou při navržených rozměrech zcela zanedbatelné. Použití standardizovaných profilů navíc umožňuje modulární konstrukci snadno přizpůsobitelnou různým typům úlů nebo budoucím rozšířením systému.

\subsection*{Návrh kamerového modulu pro monitorování letáku}
Kamerový modul slouží k~vizuálnímu monitorování česna a vychází z~konstrukce navržené v~předchozí bakalářské práci \cite{Chovancova2025}, kterou jsem upravila pro rozměry domácího úlu. 3D model byl vytvořen v~prostředí SolidWorks (viz obrázek \ref{fig:3d_model_krabicky}).
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

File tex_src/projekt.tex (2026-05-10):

%==============================================================================
% Tento soubor použijte jako základ
% This file should be used as a base for the thesis
% Autoři / Authors: 2008 Michal Bidlo, 2022 Jaroslav Dytrych, 2025 Petr Veigend
% Kontakt pro dotazy a připomínky: sablona@fit.vutbr.cz
% Contact for questions and comments: sablona@fit.vutbr.cz
%==============================================================================
% kódování: UTF-8 (zmena prikazem iconv, recode nebo cstocs)
% encoding: UTF-8 (you can change it by command iconv, recode or cstocs)
%------------------------------------------------------------------------------
% zpracování / processing: make, make pdf, make clean
%==============================================================================
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

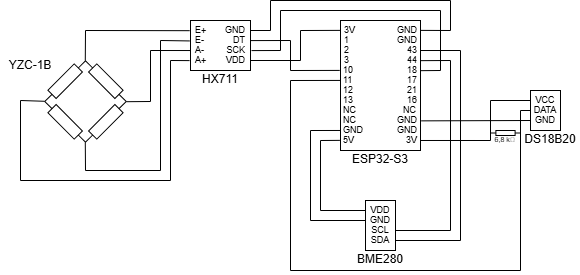
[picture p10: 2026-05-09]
docs/schematic.png

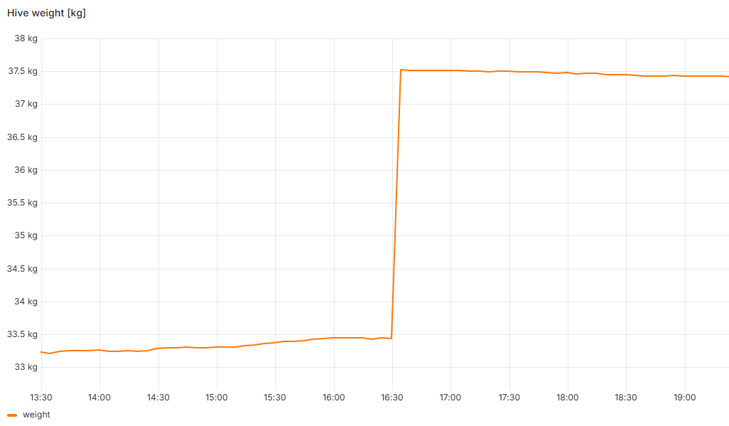
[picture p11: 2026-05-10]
tex_src/obrazky-figures/grafana_hmotnost_krmeni.png

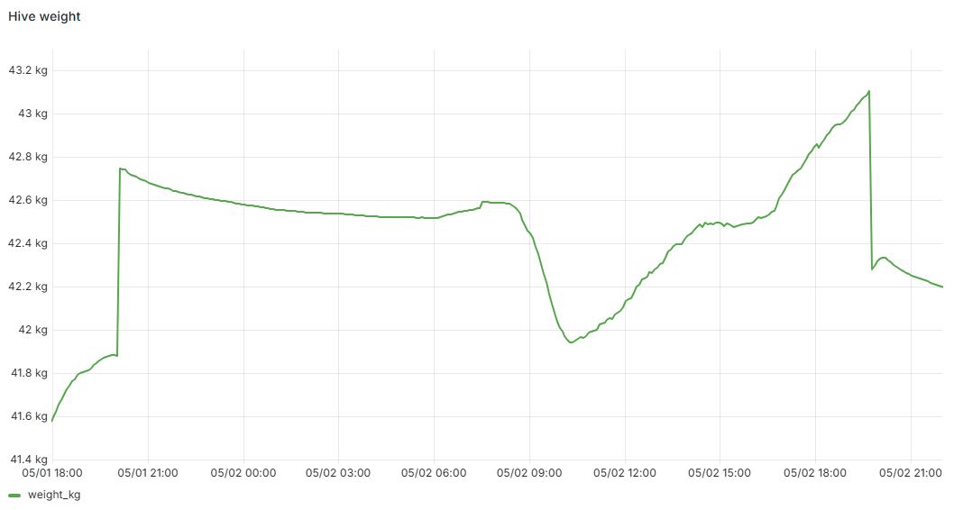
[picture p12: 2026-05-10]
tex_src/obrazky-figures/grafana_hmotnost_kamera.png

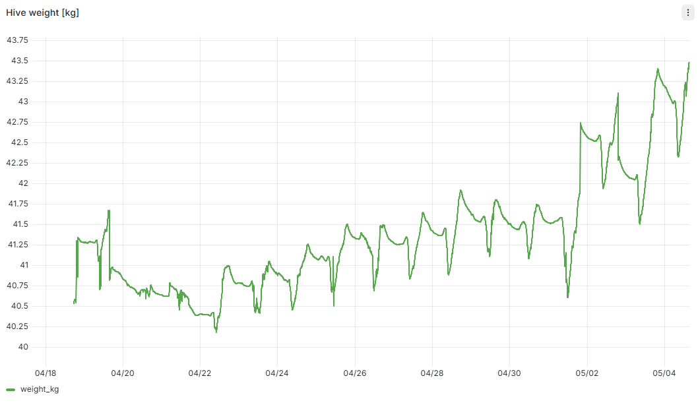
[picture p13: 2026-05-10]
tex_src/obrazky-figures/grafana_hmotnost.png

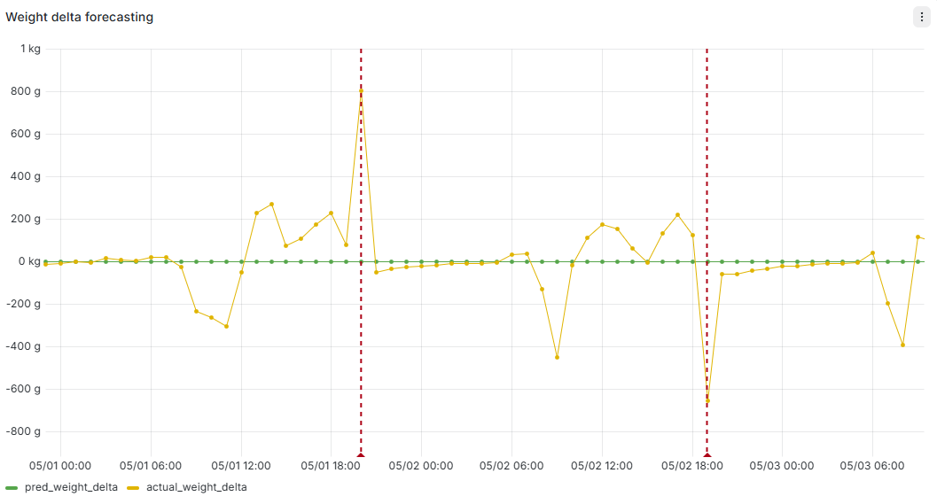
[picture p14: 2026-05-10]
tex_src/obrazky-figures/grafana_hmotnost_anomalie.png

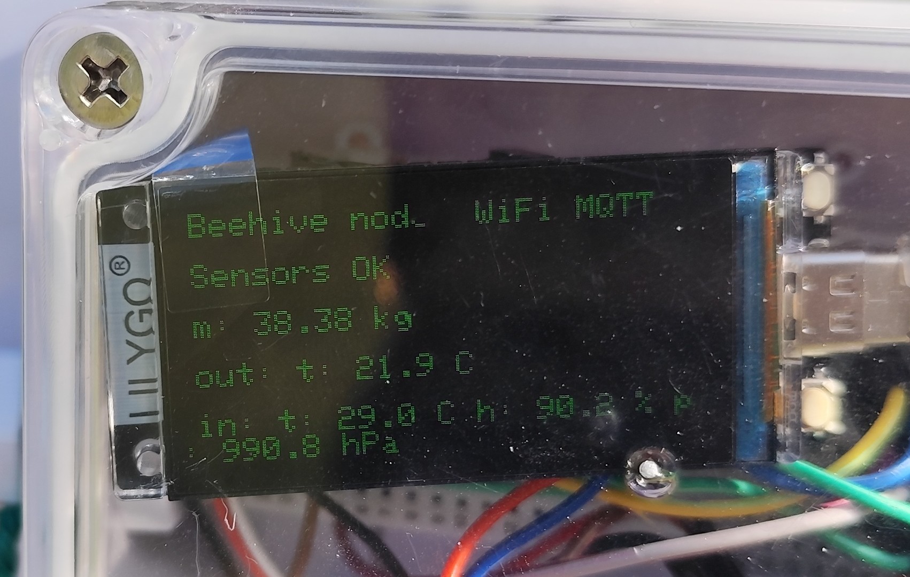
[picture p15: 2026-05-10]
tex_src/obrazky-figures/ESP32_displej.jpg

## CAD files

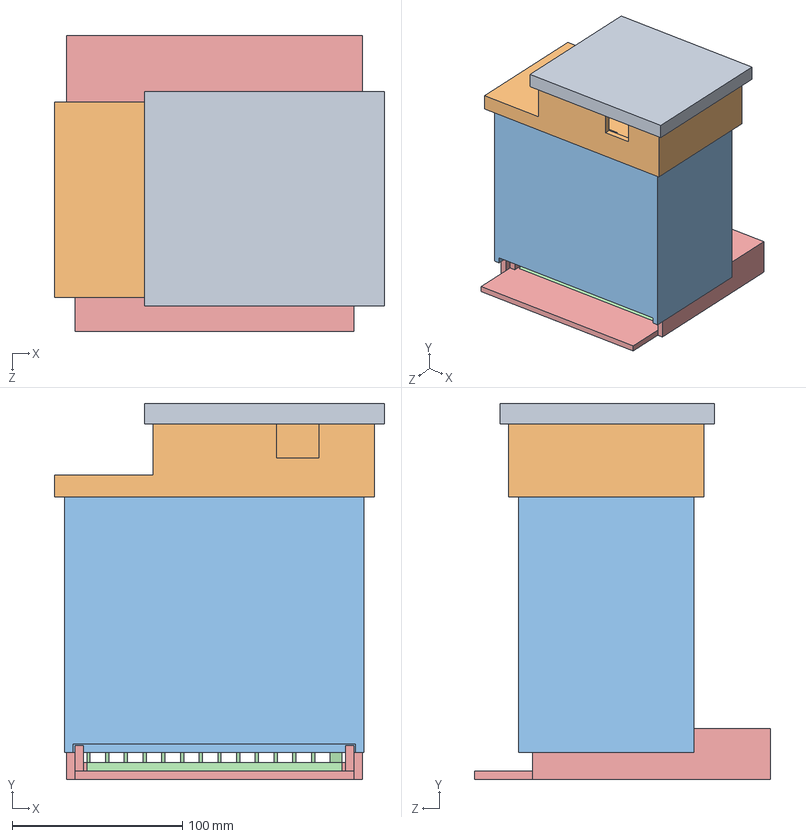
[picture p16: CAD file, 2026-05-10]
src/3d_models/kamerovy_modul.SLDASM
194.0 x 221.0 x 174.0 mm
spodni_cast
pruchod
obvodove_steny
horni_cast
strecha

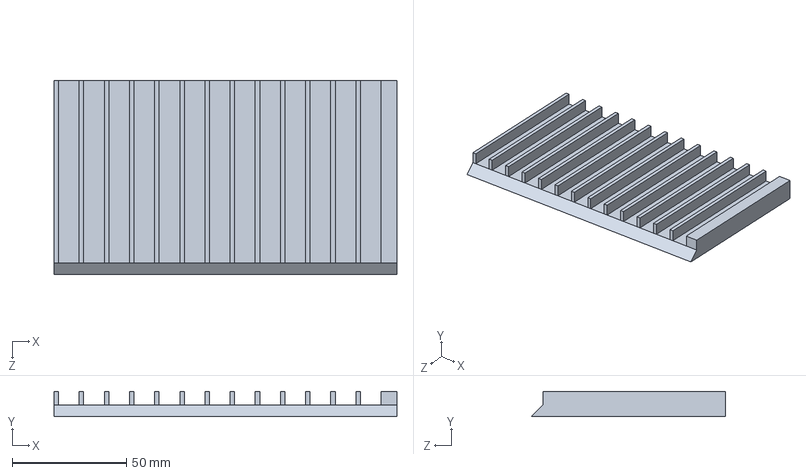
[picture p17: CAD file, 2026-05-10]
src/3d_models/pruchod.SLDPRT
150.0 x 11.0 x 85.0 mm

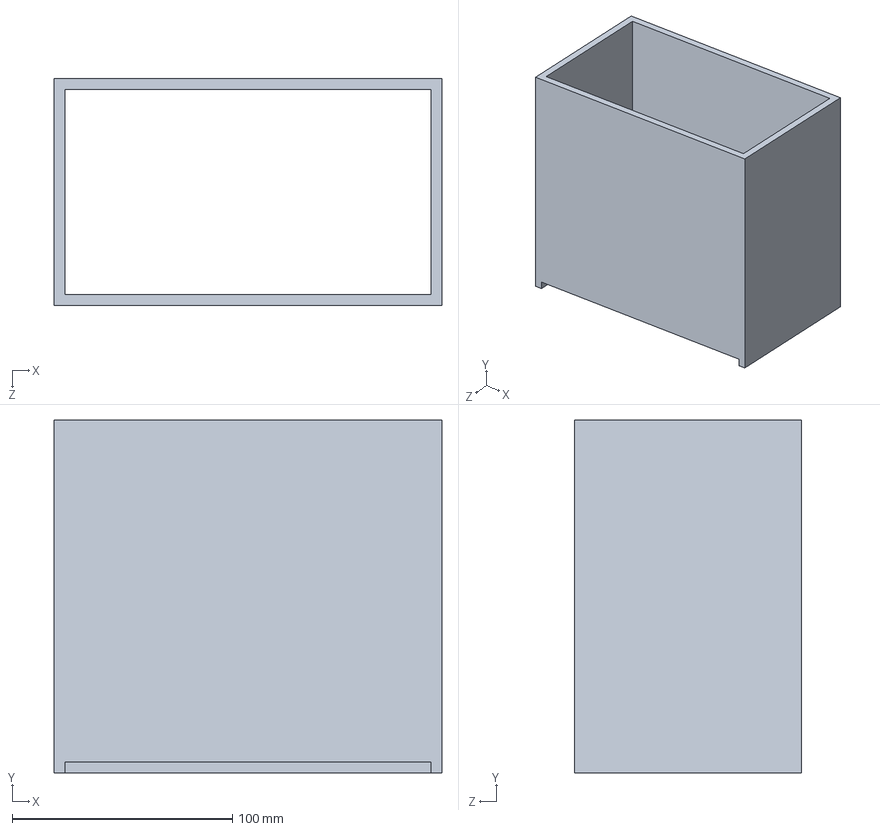
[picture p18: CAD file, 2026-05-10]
src/3d_models/obvodove_steny.SLDPRT
176.0 x 160.0 x 103.0 mm

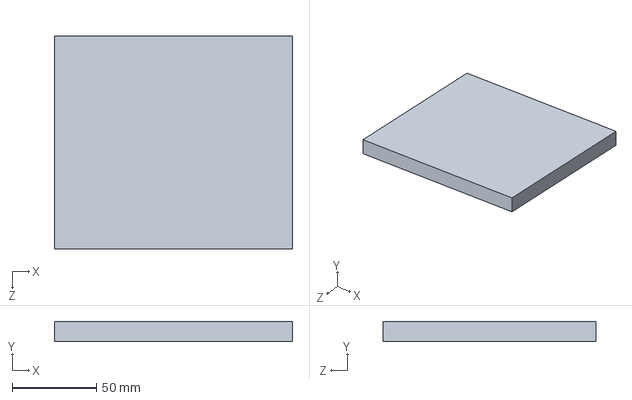
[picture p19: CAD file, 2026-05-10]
src/3d_models/strecha.SLDPRT
141.0 x 12.0 x 126.0 mm

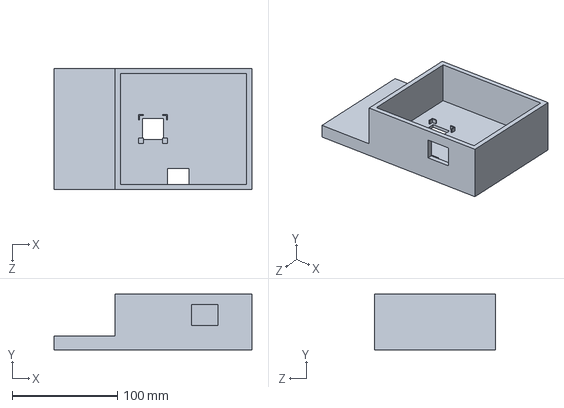
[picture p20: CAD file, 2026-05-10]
src/3d_models/horni_cast.SLDPRT
188.0 x 53.0 x 115.0 mm

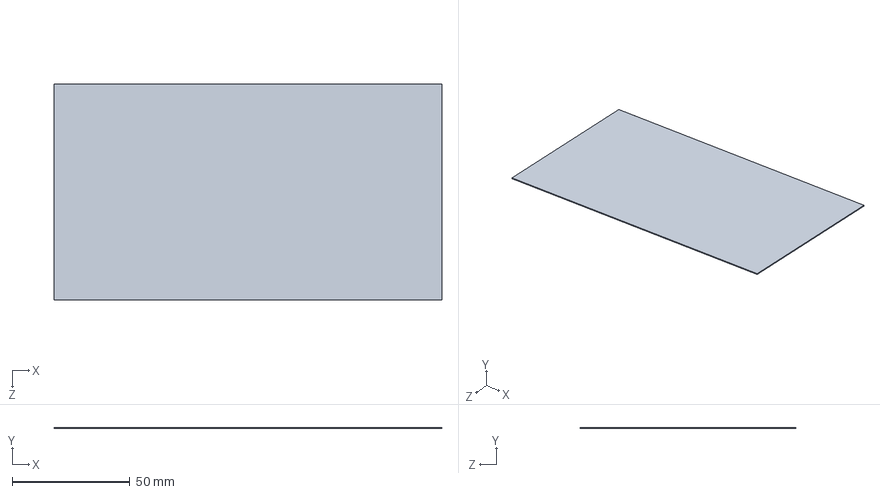
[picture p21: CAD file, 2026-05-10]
src/3d_models/difuzni_vrstva.SLDPRT
165.0 x 0.5 x 92.0 mm

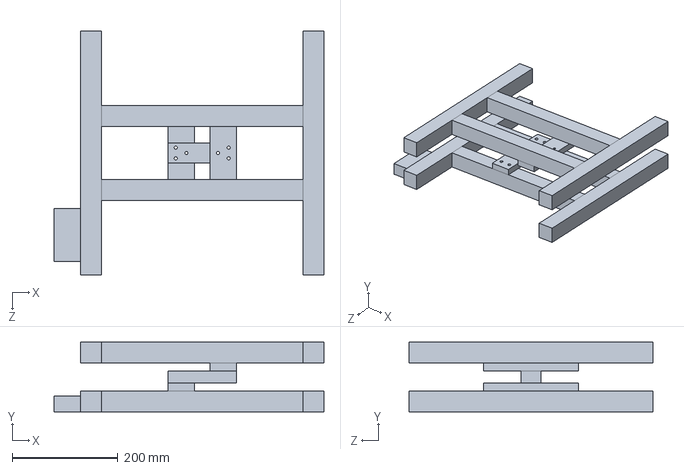
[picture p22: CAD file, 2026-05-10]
src/3d_models/ulova_vaha.SLDPRT
510.0 x 132.0 x 460.0 mm

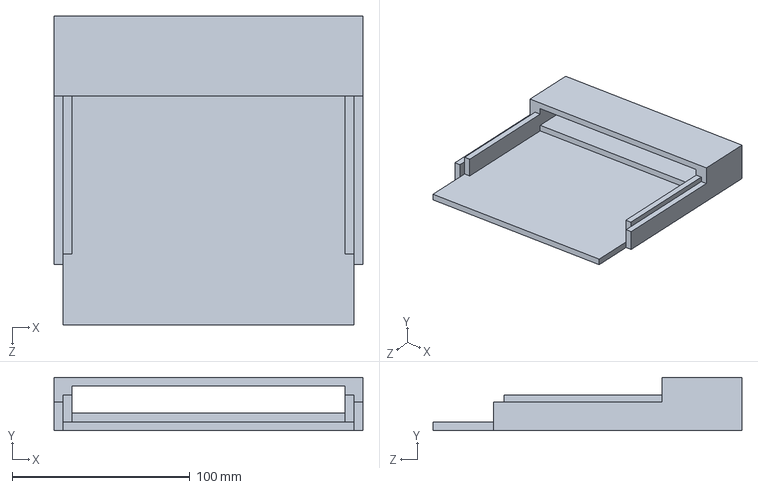
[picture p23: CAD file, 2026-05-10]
src/3d_models/spodni_cast.SLDPRT
174.0 x 30.0 x 174.0 mm

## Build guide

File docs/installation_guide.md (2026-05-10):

# Installation Guide

## Sensor Node (ESP32-S3)

### Prerequisites

- 64-bit Linux system
- USB-C cable capable of data transfer (not charge-only)
- LilyGO TTGO T-Display-S3 board

### Install Arduino IDE

- Download `arduino-ide_2.3.8_Linux_64bit.AppImage` from the official Arduino website: https://www.arduino.cc/en/software
- Make it executable:
  ```bash
  chmod +x arduino-ide_2.3.8_Linux_64bit.AppImage
  ```
- Run it:
  ```bash
  ./arduino-ide_2.3.8_Linux_64bit.AppImage
  ```

### Serial Port Permissions

- Add your user to the `dialout` group:
  ```bash
  sudo usermod -aG dialout $USER
  ```
- Log out and back in for the change to take effect
- Without this step, Arduino IDE will not be able to access the serial port
- For more information see: https://support.arduino.cc/hc/en-us/articles/360016495679-Fix-port-access-on-Linux

### Add ESP32 Board Support

- Open **File → Preferences**
- Add the following URL to the **Additional boards manager URLs** field:
  ```
  https://raw.githubusercontent.com/espressif/arduino-esp32/gh-pages/package_esp32_index.json
  ```
- Open **Tools → Board → Boards Manager**
- Search for `esp32` and install **esp32 by Espressif Systems**

### Configure Board and Upload Settings

- **Tools → Board** → select `ESP32S3 Dev Module`
- **Tools → Port** → select the port for the connected board (e.g. `/dev/ttyACM0`)
- **Tools → USB CDC on Boot** → `Enabled`
- **Tools → USB Mode** → `Hardware CDC and JTAG`

### Install Required Libraries

- Open **Tools → Manage Libraries**
- When prompted, always choose to install all dependencies
- Install the following libraries:
  - `TFT_eSPI` by Bodmer
  - `HX711 Arduino Library` by Bogdan Necuda, Andreas Motl
  - `DHT sensor library` by Adafruit
  - `Adafruit BME280 Library` by Adafruit
  - `Adafruit Unified Sensor` by Adafruit
  - `OneWire` by Paul Stoffregen
  - `DallasTemperature` by Miles Burton
  - `PubSubClient` by Nick O'Leary

### Configure TFT_eSPI for LilyGO T-Display-S3

- Locate the library folder, typically `~/Arduino/libraries/TFT_eSPI/`
- Open `User_Setup_Select.h` in a text editor
- Comment out the default line:
  ```cpp
  // #include <User_Setup.h>
  ```
- Uncomment the line for the T-Display-S3:
  ```cpp
  #include <User_Setups/Setup206_LilyGo_T_Display_S3.h>
  ```
- Save the file — without this step the display will not work

### Configure Credentials

- Copy `config.h.example` to `config.h`:
  ```bash
  cp config.h.example config.h
  ```
- Open `config.h` and fill in your WiFi SSID, password, and MQTT broker details

### Flash the Sketch

- Open `beehive.ino` in Arduino IDE
- Click **Upload** (→)
- If the upload fails, close the Serial Monitor and Serial Plotter and try again

---

## Camera Node (Raspberry Pi 5)

### Prerequisites

- Raspberry Pi 5 running Raspberry Pi OS (64-bit)
- Raspberry Pi Camera 3 connected via CSI ribbon cable
- Python 3.13.5 (pre-installed on Raspberry Pi OS)

### Install Tailscale (VPN)

- Install Tailscale:
  ```bash
  curl -fsSL https://tailscale.com/install.sh | sh
  ```
- Connect to your Tailscale network:
  ```bash
  sudo tailscale up
  ```

### Create a Virtual Environment

- The virtual environment must be created with access to system-wide packages
  so that `picamera2` and `libcamera`, which are pre-installed on Raspberry Pi OS,
  are available without reinstalling them:
  ```bash
  python3 -m venv --system-site-packages ~/Desktop/beehive/.venv
  ```
- Activate the virtual environment:
  ```bash
  source ~/Desktop/beehive/.venv/bin/activate
  ```

### Install Python Dependencies

- Install the required packages into the virtual environment:
  ```bash
  pip install -r requirements.txt
  ```
  The `requirements.txt` file is included in the repository and contains:
  - `ultralytics` — YOLO model inference and ByteTrack multi-object tracking
  - `paho-mqtt` — MQTT client
  - `opencv-python` — video capture and frame processing

### Set Up the YOLO Model

- Unzip the model from the repository:
  ```bash
    unzip src/models/mybeesyolo11.ncnn.zip -d ~/Desktop/beehive/
  ```
  The model must be located at `~/Desktop/mybeesyolo11.ncnn/best_ncnn_model` to match the `MODEL_PATH` defined in `bee_counter.py`.

### Configure Credentials

- Copy `config.py.example` to `config.py`:
  ```bash
  cp config.py.example config.py
  ```
- Open `config.py` and fill in your MQTT broker IP address and other details

## Server (Raspberry Pi 4)

### Prerequisites

- Raspberry Pi 4 running Raspberry Pi OS (64-bit)
- Python 3.13.5 (pre-installed on Raspberry Pi OS)

### Install Tailscale (VPN)

- Install Tailscale:
  ```bash
  curl -fsSL https://tailscale.com/install.sh | sh
  ```
- Connect to your Tailscale network:
  ```bash
  sudo tailscale up
  ```

### Install Mosquitto (MQTT Broker)

- Install Mosquitto:
  ```bash
  sudo apt install mosquitto mosquitto-clients
  ```
- Copy the broker configuration file from the repository:
  ```bash
  sudo cp src/config/mosquitto-beehive.conf /etc/mosquitto/conf.d/beehive.conf
  ```
- Enable and start the Mosquitto service:
  ```bash
  sudo systemctl enable mosquitto
  sudo systemctl start mosquitto
  ```

### Install SQLite

- Install SQLite:
  ```bash
  sudo apt install sqlite3
  ```
- Create the database directory and set permissions so the script can write to it:
  ```bash
  sudo mkdir -p /var/lib/beehive
  sudo chown pi:pi /var/lib/beehive
  ```
  The directory is owned by the `pi` user to avoid permission issues when the
  subscriber script writes to the database.

### Install Grafana

- Install Grafana following the official instructions for Raspberry Pi:
  https://grafana.com/docs/grafana/latest/setup-grafana/installation/debian/
- Enable and start Grafana:
  ```bash
  sudo systemctl enable grafana-server
  sudo systemctl start grafana-server
  ```
- Grafana is available at `http://localhost:3000` (default credentials: `admin` / `admin`)

### Configure Grafana SMTP (Email Alerts)

- Open the Grafana configuration file:
  ```bash
  sudo nano /etc/grafana/grafana.ini
  ```
- Find the `[smtp]` section and fill in your credentials based on the example
  in `src/config/grafana.ini.smtp.example`
- Restart Grafana to apply the changes:
  ```bash
  sudo systemctl restart grafana-server
  ```

### Import Grafana Dashboard

- Log in to Grafana at `http://localhost:3000`
- Go to **Dashboards → New → Import**
- Upload `src/config/Beekeeper5_grafana_export.json`

### Create a Virtual Environment

- Create the virtual environment with access to system-wide packages:
  ```bash
  python3 -m venv --system-site-packages /home/pi/beehive/venv
  ```
- Activate the virtual environment:
  ```bash
  source /home/pi/beehive/venv/bin/activate
  ```

### Install Python Dependencies

- Install the required packages:
  ```bash
  pip install -r requirements.txt
  ```
  The server requires: `paho-mqtt`, `lightgbm`, `numpy`, `pandas`.

### Set Up the LightGBM Models

- Copy the model files from the repository to the expected location:
  ```bash
  cp -r src/models/lgb_* /home/pi/beehive/models/
  ```
  The models must be located at `/home/pi/beehive/models/` to match the paths
  defined in `forecast_anomaly_detection.py`.

### Set Up the Subscriber Service

- Copy the service file from the repository:
  ```bash
  sudo cp src/config/beehive-subscriber.service /etc/systemd/system/
  ```
- Reload systemd and enable the service:
  ```bash
  sudo systemctl daemon-reload
  sudo systemctl enable beehive-subscriber
  sudo systemctl start beehive-subscriber
  ```
- Verify it is running:
  ```bash
  sudo systemctl status beehive-subscriber
  ```

### Set Up the Cron Job

- Open the crontab editor:
  ```bash
  crontab -e
  ```
- Add the following line (also available in `src/config/crontab.example`):
  ```
  */15 * * * * /home/pi/beehive/venv/bin/python3 /home/pi/beehive/forecast_anomaly_detection.py >> /home/pi/beehive/anomalies.log 2>&1
  ```

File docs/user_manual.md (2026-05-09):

# User Manual

## Sensor Node (ESP32-S3)

### Overview

- Once flashed and wired according to the `schematic.png`, the device runs fully autonomously
- No regular interaction is required

### Monitoring

- **Display** - the built-in TFT display shows current weight, outdoor temperature, indoor temperature/humidity/pressure, and WiFi/MQTT connection status
- **Grafana** - sensor readings are published to the MQTT broker every 5 minutes and can be viewed in the Grafana dashboard

### Taring the Scale *(one-time, only if needed)*

- Remove any weight from the scale
- Connect to the board via Serial Monitor at baud rate `115200`
- Send `t` / `T` - the zero offset is recalculated and stored automatically

### Calibrating the Scale *(one-time, only if needed)*

- The default calibration values in the sketch were obtained during initial setup and should work without any changes
- If recalibration is needed:
  - Set `KNOWN_MASS` in `beehive.ino` to the exact mass of your reference weight in kilograms
  - Place the reference weight on the scale
  - Connect via Serial Monitor at baud rate `115200` and send `c` / `C`

### Troubleshooting

- **Display shows `BME280 ERROR`** - check the I2C wiring (SDA, SCL, VCC, GND)
- **Display shows `DS18B20 error`** - check the 1-Wire wiring and the pull-up resistor
- **WiFi/MQTT indicators red** - check network credentials in `config.h` and verify the broker is reachable
- **Upload fails** - close the Serial Monitor and Serial Plotter and try again

---

## Camera Node (Raspberry Pi 5)

### Overview

- Once set up, the bee counter runs manually by activating the virtual environment and launching the script
- Counts are published to the MQTT broker every 5 minutes and logged locally to a CSV file

### Running the Bee Counter

- Activate the virtual environment:
  ```bash
  source ~/Desktop/beehive/.venv/bin/activate
  ```
- Run the script:
  ```bash
  python3 ~/Desktop/beehive/bee_counter.py
  ```
- Stop it at any time with `Ctrl+C` - a final MQTT publish is sent automatically before the script exits

### Monitoring

- **Grafana** - bee traffic counts (bees in, bees out, pollen carriers) are published to the MQTT broker and can be viewed in the Grafana dashboard
- **CSV log** - every crossing event is logged locally to `~/Desktop/beehive/bee_count_log.csv` as a backup

### Debug Output

- While running, the script prints a status line every 5 seconds:
  ```
  [DEBUG] FPS: 14.3 | tracked: 4 | CPU temp: 61.2 °C
  ```
- On exit, a CPU temperature summary is printed:
  ```
  [DEBUG] Temperature - min: 58.1 °C  avg: 62.4 °C  max: 71.3 °C
  ```

### Troubleshooting

- **`MQTT connection failed at startup`** - check the broker IP in `config.py` and verify the broker is reachable; counting and CSV logging will continue regardless
- **Low FPS in debug output** - YOLO inference is CPU-bound; ensure no other heavy processes are running on the Raspberry Pi
- **Model not found error** - verify the model is located at `~/Desktop/mybeesyolo11.ncnn/best_ncnn_model`
- **Camera not detected** - verify the CSI ribbon cable is properly seated and the camera is enabled in `raspi-config`

## Server (Raspberry Pi 4)

### Overview

- The server runs fully autonomously once set up - no regular interaction is required
- The subscriber service starts automatically on boot and stores all incoming sensor and camera readings into the SQLite database
- The forecast and anomaly detection script runs every 15 minutes via cron and sends an email alert when an anomaly is detected

### Monitoring

- **Grafana** - available at `http://localhost:3000` or via Tailscale at `http://<rpi4-tailscale-ip>:3000`
- The main dashboard displays all sensor readings, predictions, and detected anomalies
- Anomalies are shown as vertical dashed lines on the weight and temperature graphs

### Checking the Subscriber Service

- Check the service status:
  ```bash
  sudo systemctl status beehive-subscriber
  ```
- View live logs:
  ```bash
  sudo journalctl -u beehive-subscriber -f
  ```
- Restart the service if needed:
  ```bash
  sudo systemctl restart beehive-subscriber
  ```

### Checking the Anomaly Detection Log

- View the anomaly detection log:
  ```bash
  tail -f /home/pi/beehive/anomalies.log
  ```

### Querying the Database

- Open the database:
  ```bash
  sqlite3 /var/lib/beehive/beehive_v2.db
  ```
- Useful queries:
  ```sql
  -- count all sensor readings
  SELECT COUNT(*) FROM readings;

  -- latest sensor reading
  SELECT * FROM readings ORDER BY timestamp DESC LIMIT 1;

  -- latest camera reading
  SELECT * FROM camera_readings ORDER BY timestamp DESC LIMIT 1;

  -- all detected anomalies
  SELECT timestamp, anomaly_weight, anomaly_temp FROM predictions
  WHERE anomaly_weight = 1 OR anomaly_temp = 1;
  ```

### Troubleshooting

- **Subscriber service not starting** - check that Mosquitto is running: `sudo systemctl status mosquitto`
- **No data in Grafana** - verify the subscriber service is running and the ESP32 is connected to the same MQTT broker
- **No anomaly detection results** - check `anomalies.log` for errors; the script requires at least 168 hours of data before it can produce predictions
- **Email alerts not sending** - verify the SMTP credentials in `/etc/grafana/grafana.ini` and restart Grafana: `sudo systemctl restart grafana-server`

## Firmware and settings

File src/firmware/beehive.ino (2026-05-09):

/**
 * @file beehive.ino
 * @brief Sensor node firmware for the beehive monitoring system.
 *
 * Reads weight (HX711 + YZC-1B load cell), outdoor temperature (DS18B20),
 * and indoor temperature, humidity, and pressure (BME280). Sensor readings
 * are displayed on the built-in TFT display and published to an MQTT broker
 * over WiFi as a JSON payload every 5 minutes.
 *
 * @details
 * Part of the bachelor's thesis at VUT FIT 2025/2026: Robotic Beekeeper.
 * The thesis deals with the design and implementation of an automated beehive monitoring system.
 *
 * @author Eliška Křeménková (xkremee00)
 * @date 20. 12. 2025
 */

#include "TFT_eSPI.h"
#include "HX711.h"
#include "OneWire.h"
#include "DallasTemperature.h"
#include "Wire.h"
#include "Adafruit_Sensor.h"
#include "Adafruit_BME280.h"
#include "WiFi.h"
#include "PubSubClient.h"
#include "config.h"

// ---------------------------------------------------------------------------
// Pin definitions
// ---------------------------------------------------------------------------

/** @brief HX711 data pin. */
static constexpr int HX_DT = 10;

/** @brief HX711 clock pin. */
static constexpr int HX_SCK = 18;

/** @brief DS18B20 1-Wire data pin. */
static constexpr int DS18B20_PIN = 11;

/** @brief I2C SDA pin for BME280. */
static constexpr int SDA_PIN = 43;

/** @brief I2C SCL pin for BME280. */
static constexpr int SCL_PIN = 44;

// ---------------------------------------------------------------------------
// Timing
// ---------------------------------------------------------------------------

/** @brief Interval between sensor reads and display updates (milliseconds). */
static constexpr unsigned long DISPLAY_INTERVAL = 2000;

/** @brief Interval between MQTT publishes (milliseconds). */
static constexpr unsigned long MQTT_INTERVAL = 5 * 60000;

// ---------------------------------------------------------------------------
// Weight filtering
// ---------------------------------------------------------------------------

/** @brief Exponential moving average (EMA) smoothing factor for weight. */
static constexpr float EMA_ALPHA = 0.2f;

// ---------------------------------------------------------------------------
// Global objects
// ---------------------------------------------------------------------------

TFT_eSPI tft;                           ///< TFT display
HX711 scale;                            ///< Load cell ADC
OneWire one_wire(DS18B20_PIN);          ///< 1-wire bus
DallasTemperature ds18b20(&one_wire);   ///< DS18B20 sensor
Adafruit_BME280 bme;                    ///< BME280 sensor
WiFiClient wifi_client;                 ///< TCP client used by MQTT
PubSubClient mqtt(wifi_client);         ///< MQTT client

// ---------------------------------------------------------------------------
// Scale calibration state
// ---------------------------------------------------------------------------

/** @brief Raw ADC reading with no load on the scale (tare offset). */
static long offset_raw = -213254;

/** @brief ADC counts per kilogram (calibration factor). */
float counts_per_kg = -39335.31f;

/** @brief Known reference mass used during calibration (kg). */
const float KNOWN_MASS = 56.5f;

// ---------------------------------------------------------------------------
// Weight filter state
// ---------------------------------------------------------------------------

float kg_filtered = 0.0f;               ///< Current EMA-filtered weight value
bool kg_filter_init = false;            ///< True after the EMA has been seeded

// ---------------------------------------------------------------------------
// Timing state
// ---------------------------------------------------------------------------

unsigned long last_display = 0;         ///< Timestamp of the last display update (ms)
unsigned long last_mqtt = 0;            ///< Timestamp of the last MQTT publish (ms)

// ---------------------------------------------------------------------------
// Scale calibration
// ---------------------------------------------------------------------------

/**
 * @brief Tares the scale by averaging 20 raw readings as the zero offset.
 *
 * Call with no load on the scale. The result is stored in offset_raw.
 * Trigger via the 't' serial command.
 */
void tare_scale() {
  Serial.println("Taring...");
  offset_raw = scale.read_average(20);
  Serial.print("Tare offset = ");
  Serial.println(offset_raw);
}

/**
 * @brief Calibrates the scale using a known reference mass.
 *
 * Call with known_kg placed on the scale. Computes and stores the
 * ADC counts-per-kilogram factor in counts_per_kg.
 * Trigger via the 'c' serial command.
 *
 * @param known_kg  Mass of the reference weight placed on the scale (kg).
 */
void calibrate_scale(float known_kg) {
  long raw = scale.read_average(20);
  counts_per_kg = (float)(raw - offset_raw) / known_kg;
  Serial.print("Cal counts_per_kg = ");
  Serial.println(counts_per_kg, 2);
}

// ---------------------------------------------------------------------------
// Weight reading
// ---------------------------------------------------------------------------

/**
 * @brief Reads and returns the current hive weight with EMA filtering.
 *
 * @param[out] kg_out  Filtered weight in kilograms.
 * @return             true if a valid reading was obtained,
 *                     false if the ADC is not ready or the scale is uncalibrated.
 */
bool read_weight(float &kg_out) {
  if (!scale.is_ready() || counts_per_kg == 0) {
    return false;
  }

  // Average 5 raw ADC readings and convert to kilograms
  float kg = (float)(scale.read_average(5) - offset_raw) / counts_per_kg;

  if (!kg_filter_init) {
    kg_filtered = kg;
    kg_filter_init = true;
  } else {
    kg_filtered = EMA_ALPHA * kg + (1.0f - EMA_ALPHA) * kg_filtered;
  }

  kg_out = kg_filtered;
  return true;
}

// ---------------------------------------------------------------------------
// WiFi
// ---------------------------------------------------------------------------

/**
 * @brief Attempts to connect to the WiFi network defined in config.h.
 *
 * Tries for up to 10 seconds (20 attempts × 500 ms). If the connection
 * cannot be established within that window, the function returns and the
 * sketch continues -- the connection will be retried by wifi_check().
 */
void wifi_connect() {
  Serial.print("Connecting to WiFi");
  WiFi.begin(WIFI_SSID, WIFI_PASS);

  int attempts = 0;
  while (WiFi.status() != WL_CONNECTED && attempts < 20) {
    delay(500);
    Serial.print(".");
    attempts++;
  }

  if (WiFi.status() == WL_CONNECTED) {
    Serial.print(" connected! IP: ");
    Serial.println(WiFi.localIP());
  } else {
    Serial.println(" failed, will retry in background.");
  }
}

/**
 * @brief Checks the WiFi connection and reconnects if it has been lost.
 */
void wifi_check() {
  if (WiFi.status() != WL_CONNECTED) {
    if (WiFi.status() != WL_DISCONNECTED) {
      WiFi.disconnect();
      delay(1000);
    }
    Serial.println("WiFi lost, reconnecting...");
    wifi_connect();
  }
}

// ---------------------------------------------------------------------------
// MQTT
// ---------------------------------------------------------------------------

/**
 * @brief Attempts to connect to the MQTT broker defined in config.h.
 *
 * Does nothing if WiFi is not connected. Tries up to 5 times with a 1-second
 * delay between attempts. If all attempts fail, the function returns and the
 * connection will be retried by mqtt_check().
 */
void mqtt_connect() {
  if (WiFi.status() != WL_CONNECTED) {
    return;
  }

  Serial.print("Connecting to MQTT broker");
  int attempts = 0;
  while (!mqtt.connected() && attempts < 5) {
    if (mqtt.connect(MQTT_ID)) {
      Serial.println(" connected!");
    } else {
      Serial.print(".");
      delay(1000);
      attempts++;
    }
  }
  if (!mqtt.connected()) {
    Serial.println(" failed, will retry later.");
  }
}

/**
 * @brief Checks the MQTT connection and reconnects if it has been lost.
 */
void mqtt_check() {
  if (!mqtt.connected()) {
    mqtt_connect();
  }
}

/**
 * @brief Publishes a sensor reading to the MQTT broker as a JSON payload.
 *
 * Published topic is defined by MQTT_TOPIC in config.h.
 *
 * Payload format:
 * {"weight":<kg>,"t_o":<°C>,"t":<°C>,"h":<%>,"p":<hPa>}
 *
 * @param m    Filtered hive weight (kg).
 * @param t_o  Outdoor temperature from DS18B20 (°C).
 * @param t_i  Indoor temperature from BME280 (°C).
 * @param h_i  Indoor relative humidity from BME280 (%).
 * @param p_i  Indoor atmospheric pressure from BME280 (hPa).
 */
void mqtt_publish(float m, float t_o, float t_i, float h_i, float p_i) {
  if (!mqtt.connected()) {
    return;
  }

  char payload[128];
  snprintf(payload, sizeof(payload),
    "{\"weight\":%.4f,\"t_o\":%.1f,\"t\":%.1f,\"h\":%.0f,\"p\":%.1f}", m, t_o, t_i, h_i, p_i);

  if (mqtt.publish(MQTT_TOPIC, payload)) {
    Serial.print("MQTT sent: ");
    Serial.println(payload);
  } else {
    Serial.println("MQTT publish failed.");
  }
}

// ---------------------------------------------------------------------------
// Display
// ---------------------------------------------------------------------------

/**
 * @brief Updates the TFT display with the latest sensor readings.
 *
 * The top-right corner shows WiFi and MQTT connection status in green
 * (connected) or red (disconnected). The main area shows weight, outdoor
 * temperature, and indoor temperature/humidity/pressure. Sensor error
 * strings are shown in place of values when a reading is invalid.
 *
 * @param m      Filtered hive weight (kg).
 * @param ok_m   true if the weight reading is valid.
 * @param t_o    Outdoor temperature (°C).
 * @param ok_ds  true if the DS18B20 reading is valid.
 * @param t_i    Indoor temperature (°C).
 * @param h_i    Indoor relative humidity (%).
 * @param p_i    Indoor atmospheric pressure (hPa).
 * @param ok_bme true if the BME280 reading is valid.
 */
void update_display(float m, bool ok_m, float t_o, bool ok_ds, float t_i, float h_i, float p_i, bool ok_bme) {
  tft.fillRect(140, 0, 100, 20, TFT_BLACK);
  tft.setCursor(180, 10);
  tft.setTextColor(WiFi.status() == WL_CONNECTED ? TFT_GREEN : TFT_RED, TFT_BLACK);
  tft.print("WiFi ");
  tft.setTextColor(mqtt.connected() ? TFT_GREEN : TFT_RED, TFT_BLACK);
  tft.print("MQTT");
  tft.setTextColor(TFT_GREEN, TFT_BLACK);

  tft.fillRect(0, 70, 240, 90, TFT_BLACK);
  tft.setCursor(10, 70);
  if (ok_m) {
    tft.printf("m: %.2f kg", m);
  } else {
    tft.println("m: --");
  }

  tft.setCursor(10, 100);
  if (ok_ds) {
    tft.printf("out: t: %.1f C", t_o);
  } else {
    tft.println("DS18B20 error");
  }

  tft.setCursor(10, 130);
  if (ok_bme) {
    tft.printf("in: t: %.1f C h: %.1f %% p: %.1f hPa", t_i, h_i, p_i);
  } else {
    tft.println("BME error");
  }
}

// ---------------------------------------------------------------------------
// Setup
// ---------------------------------------------------------------------------

/**
 * @brief Initialises all peripherals and establishes network connections.
 *
 * Execution order: display → load cell → DS18B20 → BME280 → WiFi → MQTT.
 * The display shows "Sensors OK" or "BME280 ERROR" depending on whether the
 * BME280 is detected. Serial commands available after setup:
 *   - t / T  Tare the scale (no load must be present).
 *   - c / C  Calibrate the scale (KNOWN_MASS must be on the scale).
 */
void setup() {
  Serial.begin(115200);
  delay(1000);

  // Display
  tft.init();
  tft.setRotation(1);
  tft.fillScreen(TFT_BLACK);
  tft.setTextSize(2);
  tft.setTextColor(TFT_GREEN, TFT_BLACK);
  tft.setCursor(10, 10);
  tft.println("Beehive node");

  // Load cell
  scale.begin(HX_DT, HX_SCK);

  // DS18B20
  ds18b20.begin();
  Serial.print("DS18B20 sensors found: ");
  Serial.println(ds18b20.getDeviceCount());

  // BME280
  Wire.begin(SDA_PIN, SCL_PIN);
  bool bme_ok = bme.begin(0x76);
  if (!bme_ok) bme_ok = bme.begin(0x77);

  tft.setCursor(10, 40);
  if (!bme_ok) {
    Serial.println("BME280 not found! Check wiring.");
    tft.setTextColor(TFT_RED, TFT_BLACK);
    tft.println("BME280 ERROR");
    tft.setTextColor(TFT_GREEN, TFT_BLACK);
  } else {
    tft.println("Sensors OK");
  }

  // WiFi
  wifi_connect();

  // MQTT
  mqtt.setServer(MQTT_HOST, MQTT_PORT);
  mqtt_connect();

  Serial.println("Commands: 't' = tare, 'c' = calibrate");
}

// ---------------------------------------------------------------------------
// Main loop
// ---------------------------------------------------------------------------

/**
 * @brief Main loop -- runs continuously after setup().
 *
 * Every iteration: checks WiFi and MQTT connections and processes the
 * PubSubClient keep-alive. Every DISPLAY_INTERVAL milliseconds: reads all
 * sensors, updates the display, and logs readings to Serial. Every
 * MQTT_INTERVAL milliseconds: publishes a JSON payload to the MQTT broker
 * if both weight and outdoor temperature readings are valid.
 */
void loop() {
  // Handle one-time commands (tare/calibration)
  if (Serial.available()) {
    char c = Serial.read();
    if (c == 't' || c == 'T') {
      tare_scale();
    } else if (c == 'c' || c == 'C') {
      calibrate_scale(KNOWN_MASS);
    }
  }

  // Check connections
  wifi_check();
  mqtt_check();
  mqtt.loop();  // Required by PubSubClient to maintain connection

  unsigned long now = millis();

  // Read sensors every 2s for display
  if (now - last_display >= DISPLAY_INTERVAL) {
    last_display = now;

    float m = 0;
    bool ok_m = read_weight(m);

    ds18b20.requestTemperatures();
    float t_o = ds18b20.getTempCByIndex(0);
    bool ok_ds = (t_o != DEVICE_DISCONNECTED_C && t_o != 85.0f);

    float t_i = bme.readTemperature();
    float h_i = bme.readHumidity();
    float p_i = bme.readPressure() / 100.0f;
    bool ok_bme = !isnan(t_i) && !isnan(h_i) && !isnan(p_i);

    if (!ok_ds) Serial.println("DS18B20 read failed");
    if (!ok_bme) Serial.println("BME280 read failed");
    if (!ok_m) Serial.println("Weight not ready/calibrated");

    update_display(m, ok_m, t_o, ok_ds, t_i, h_i, p_i, ok_bme);

    // MQTT publish every 5 minutes
    if (now - last_mqtt >= MQTT_INTERVAL) {
      last_mqtt = now;
      if (ok_m && ok_ds) {
        mqtt_publish(m, t_o, t_i, h_i, p_i);
      }
    }
  }
}

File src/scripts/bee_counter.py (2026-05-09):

"""
bee_counter.py
---------
Real-time bee traffic counter for the beehive monitoring system.

Captures video from the Raspberry Pi Camera 3, runs a YOLO object detection
model with ByteTrack multi-object tracking, and counts bees crossing a
horizontal line at the hive entrance. Distinguishes between bees entering
and leaving, and tracks pollen-carrying bees separately. Aggregated counts
are published to an MQTT broker every PUBLISH_INTERVAL_MIN minutes and logged
to a CSV file for local backup.

Part of the bachelor's thesis at VUT FIT 2025/2026: Robotic Beekeeper.
The thesis deals with the design and implementation of an automated beehive monitoring system.

Author:     Eliška Křeménková (xkremee00)
Date:       8. 4. 2026
"""

from picamera2 import Picamera2
from datetime import datetime
from pathlib import Path
from libcamera import controls
from ultralytics import YOLO
import cv2
import csv
import time
import json
import paho.mqtt.client as mqtt

from config import (MQTT_HOST, MQTT_PORT, MQTT_ID, MQTT_TOPIC, PUBLISH_INTERVAL_MIN)

# ---------------------------------------------------------------------------
# CONFIG
# ---------------------------------------------------------------------------

LENS_POSITION = 5.0         # manual focus position: 1 / distance in metres (5.0 ≈ 20 cm)
TARGET_FPS = 15             # target capture and inference rate
CROP = (0, 0, 2304, 1296)   # region of interest (left, top, right, bottom) in pixels
LINE_FRACTION = 1 / 2       # vertical position of the counting line as a fraction of frame height
CONFIDENCE = 0.4            # minimum YOLO detection confidence threshold

MODEL_PATH = Path.home() / "Desktop" / "mybeesyolo11.ncnn" / "best_ncnn_model"
LOG_FILE = Path.home() / "Desktop" / "bee_count_log.csv"

# YOLO class index to name mapping (must match the trained model)
CLASS_NAMES = {
    0: "bee",
    1: "bee_pollen",
}

BEE_CLASSES = {"bee", "bee_pollen"}
POLLEN_CLASSES = {"bee_pollen"}

PUBLISH_INTERVAL_SEC = PUBLISH_INTERVAL_MIN * 60
DEBUG_INTERVAL_SEC = 5

# ---------------------------------------------------------------------------
# DERIVED CONSTANTS
# ---------------------------------------------------------------------------

crop_left, crop_top, crop_right, crop_bottom = CROP
crop_h = crop_bottom - crop_top

# Y coordinate of the horizontal counting line in cropped frame pixels
LINE_Y = int(crop_h * LINE_FRACTION)

# minimum time between captured frames to maintain TARGET_FPS
FRAME_INTERVAL = 1.0 / TARGET_FPS

# ---------------------------------------------------------------------------
# MQTT SETUP
# ---------------------------------------------------------------------------

mqtt_connected = False

def on_connect(client, userdata, connect_flags, reason_code, properties=None):
    """Called by the MQTT client when a connection attempt completes."""
    global mqtt_connected
    if reason_code == 0:
        mqtt_connected = True

def on_disconnect(client, userdata, disconnect_flags, reason_code, properties=None):
    """Called by the MQTT client when the connection is lost."""
    global mqtt_connected
    mqtt_connected = False

mqtt_client = mqtt.Client(mqtt.CallbackAPIVersion.VERSION2, client_id=MQTT_ID)
mqtt_client.on_connect = on_connect
mqtt_client.on_disconnect = on_disconnect

try:
    mqtt_client.connect(MQTT_HOST, MQTT_PORT)
    mqtt_client.loop_start()
except Exception as e:
    # not fatal — script will keep counting and saving CSV even without broker
    print(f"MQTT connection failed at startup: {e}")

# ---------------------------------------------------------------------------
# LOAD MODEL
# ---------------------------------------------------------------------------

model = YOLO(str(MODEL_PATH), task="detect")

# ---------------------------------------------------------------------------
# TRACKING STATE
# ---------------------------------------------------------------------------

# per-track history: {track_id: {"y": float, "cls": str, "frames": int}}
track_history = {}

# IDs that have already been counted to avoid double-counting
counted_ids = set()

# interval counts -- accumulate between publishes, then reset after each publish
counts = {
    "bees_in": 0,
    "bees_out": 0,
    "pollen_in": 0,
}

# ---------------------------------------------------------------------------
# CSV LOG SETUP
# ---------------------------------------------------------------------------

write_header = not LOG_FILE.exists()
log = open(LOG_FILE, "a", newline="")
writer = csv.writer(log)
if write_header:
    writer.writerow([
        "timestamp",
        "event",
        "direction",
        "class",
        "bees_in_total",
        "bees_out_total",
        "pollen_in_total",
    ])
    log.flush()

# running totals for CSV (never resets)
totals = {"bees_in": 0, "bees_out": 0, "pollen_in": 0}

# ---------------------------------------------------------------------------
# HELPER FUNCTIONS
# ---------------------------------------------------------------------------

def log_crossing(direction, cls_name):
    """Append a single crossing event to the CSV log."""
    writer.writerow([
        datetime.now().strftime("%Y-%m-%d %H:%M:%S"),
        "crossing",
        direction,
        cls_name,
        totals["bees_in"],
        totals["bees_out"],
        totals["pollen_in"],
    ])
    log.flush()

def publish_counts():
    """Publish aggregated counts for the last interval to MQTT, then reset them."""
    payload = json.dumps({
        "bees_in": counts["bees_in"],
        "bees_out": counts["bees_out"],
        "pollen_in": counts["pollen_in"],
    })

    if mqtt_connected:
        mqtt_client.publish(MQTT_TOPIC, payload, qos=0)

    # reset interval counts regardless of whether publish succeeded
    counts["bees_in"] = 0
    counts["bees_out"] = 0
    counts["pollen_in"] = 0

def read_cpu_temp():
    """Read the Raspberry Pi CPU temperature from the system thermal zone.

    Returns:
        float: CPU temperature in °C, or 0.0 if unavailable.
    """
    try:
        temp_str = Path("/sys/class/thermal/thermal_zone0/temp").read_text()
        return int(temp_str.strip()) / 1000.0
    except Exception:
        return 0.0

# ---------------------------------------------------------------------------
# CAMERA SETUP
# ---------------------------------------------------------------------------

# camera size matches the CROP region -- RGB888 required by OpenCV
camera = Picamera2()
config = camera.create_video_configuration(
    main={
        "size": (2304, 1296),
        "format": "RGB888",
    },
    controls={
        "AfMode": controls.AfModeEnum.Manual,
        "LensPosition": LENS_POSITION,
        "FrameRate": TARGET_FPS,
    }
)
camera.configure(config)
camera.start()
time.sleep(2) # allow the camera to stabilise before the first capture

# ---------------------------------------------------------------------------
# MAIN LOOP
# ---------------------------------------------------------------------------
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

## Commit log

2026-05-10 added used 3D models
    [difuzni_vrstva.SLDPRT, horni_cast.SLDPRT, kamerovy_modul.SLDASM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]
2026-05-10 added dataset and pynb used for model training
    [49.csv]
2026-05-10 added my collected data
    [bee_count_log.csv, sensor_data.csv]
2026-05-12 anomaly detection stopped working, small fixes
    [forecast_anomaly_detection.py]
